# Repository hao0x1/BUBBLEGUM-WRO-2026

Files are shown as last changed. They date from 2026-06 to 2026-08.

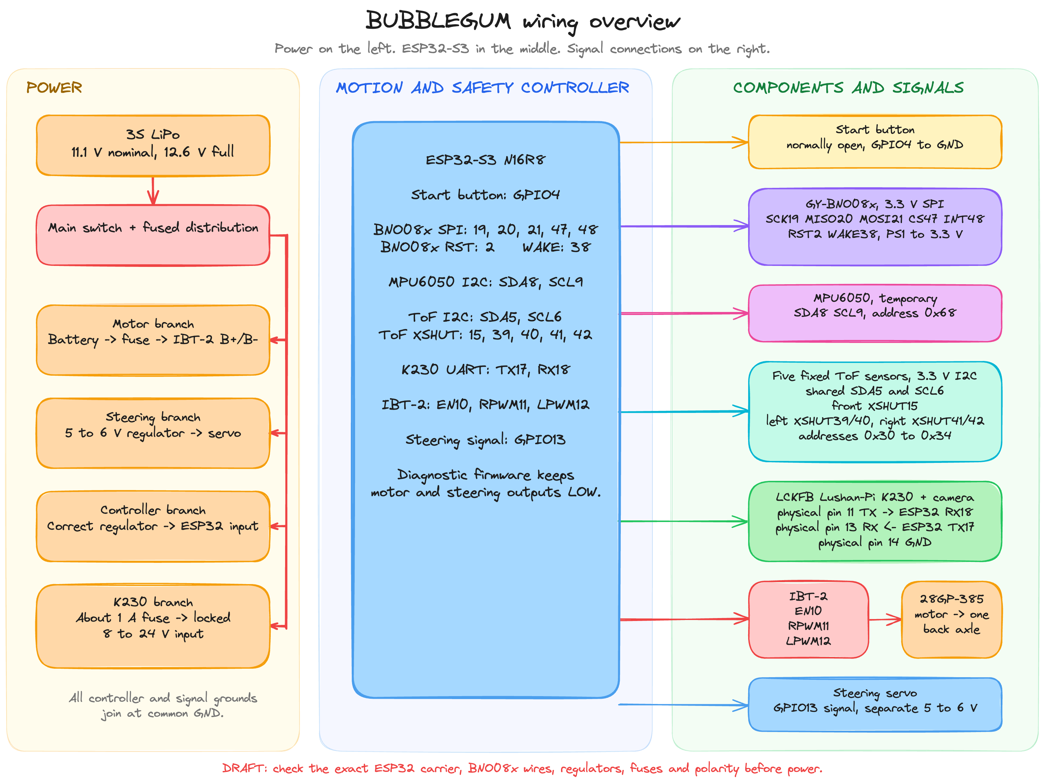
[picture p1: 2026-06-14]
schemes/wiring-overview.png

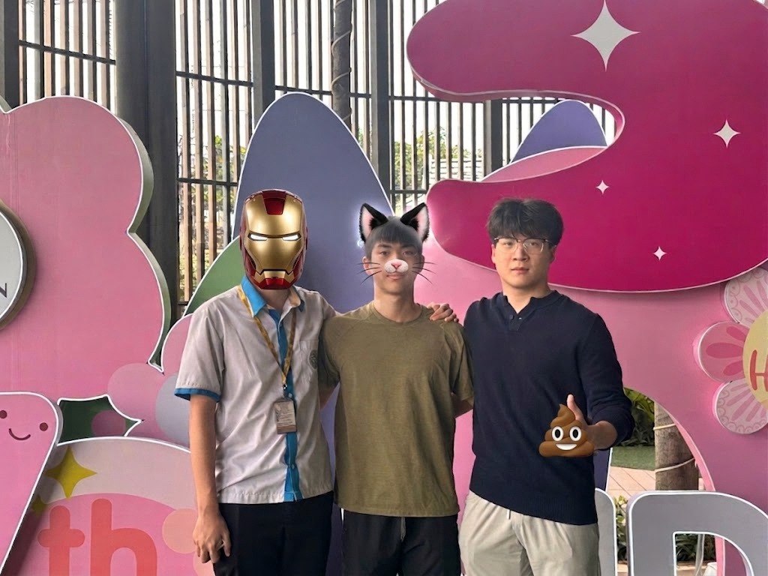
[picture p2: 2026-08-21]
t-photos/funny_img.jpeg

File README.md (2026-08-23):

# BUBBLEGUM WRO Future Engineers 2026

Competition source and field tools for our ESP32-S3 / Lushan-Pi K230 car.

**Start here: [competition/QUICK_START.md](competition/QUICK_START.md).** It contains the exact upload and logging commands for both rounds. No assistant or internet access is needed on the prepared laptop.

## Which version to use

| Round / board | Selection | Evidence |
| --- | --- | --- |
| Open — ESP32 | `autonomousOpen`, R18 configuration | Previously completed 12 corners / three laps in the physical Open test. Speed settings are unchanged. |
| Obstacle — ESP32 | `autonomousObstacle`, R42 | Latest recovery/progress revision; built and host-tested, awaiting its field run. Three laps, normal start, no parking. |
| Either round — K230 | [main.py](src/LCKFB-Lushan-Pi-K230/main.py) | Same production camera program for both rounds. Existing SD colour calibration is preserved. |

From this repository on the prepared Mac:

```sh
./competition/field.sh open
```

or:

```sh
./competition/field.sh obstacle
```

Each command builds/uploads the selected ESP32 profile and opens a passive log. The car waits for its physical start button. Wait for the logger's `READY` message, then press the start button once. `READY` confirms `WAIT_BUTTON` with healthy telemetry and no controller or actuator fault. Logs are saved in `local/logs/`.

## Current behavior

The ESP32 reads five ToF distance sensors and an XMS-A5/BNO055 heading sensor, drives the steering servo and motor, and counts verified corner exits. Twelve corners form three laps. The K230 reports red/green image observations over UART; it does not command motors.

Open uses its existing R18 speed and corner settings. Obstacle uses 400-permille straight power, 450 for tight corners, and 300 for bounded reverse. It follows live red-right / green-left guidance when usable, continues through measured free space when a target disappears, and attempts recovery when blocked. Pillar-section learning is disabled; a known failed target is briefly suppressed after reversing to avoid immediately repeating the same maneuver. Distance sensors remain active during that suppression. Parking and parking-lot departure are not part of this competition revision.

The front-left/front-right sensors are mounted narrower than the rear pair; the four side rays point outward at approximately 45 degrees. Their raw front-minus-rear distances are not treated as calibrated wall angles. The source pin mapping is in [boardConfig.h](src/ESP32-S3-N16R8/include/boardConfig.h).

## Repository layout

- [src/ESP32-S3-N16R8](src/ESP32-S3-N16R8): current PlatformIO controller, sensors, actuators and configuration.
- [src/LCKFB-Lushan-Pi-K230](src/LCKFB-Lushan-Pi-K230): production camera program.
- [competition](competition): short field guide and upload/log command.
- [tools](tools): portable logger, K230 installer/calibrator and offline checks.
- [tests](tests): host regression tests for the controller and actuator driver.
- [competition.md](competition.md): supplied competition reference.
- [models](models), [schemes](schemes), [other](other): CAD, wiring drawings and component records.
- [t-photos](t-photos), [v-photos](v-photos), [video](video): team/vehicle photos and driving-video link.
- `local/`: ignored logs, firmware copies, old experiments, backups and private test records. Keep this folder on the laptop; it is excluded from Git.

Some hardware drawings and component records predate the latest electronics changes. The current source and field guide identify the configuration prepared for this run.

## Offline checks

```sh
./tools/check.sh
./competition/field.sh build
```

Host tests exercise state transitions, mirrored steering, recovery timing and three-lap completion. They do not establish a successful physical Obstacle run. The field guide identifies the remaining physical verification. No Git commit or push is performed by the field tools.

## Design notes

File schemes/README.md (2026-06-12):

# Wiring

This is the working wiring map for our car. It matches the wiring we are checking now.

The readable overview is in [`wiring-overview.png`](wiring-overview.png). We can edit the original drawing in [`wiring-overview.excalidraw`](wiring-overview.excalidraw).

Do not power the car from this page yet. We still need a clear ESP32 carrier photo and a yes/no check of the soldered BNO08x wires. The current firmware is safe diagnostics only, but a wrong pin map can still damage two outputs connected together.

## Start button

The button goes between GPIO4 and GND:

```text
ESP32 GPIO4 ---- normally-open button ---- GND
```

The button has no positive or negative side. On a four-leg tactile button, two legs can already be connected inside. Use a multimeter and choose one leg from each different contact group. The selected legs must be open when released and near 0 ohms only while pressed.

The ESP32 uses `INPUT_PULLUP`:

| Button state | GPIO4 reading |
|---|---|
| Released | HIGH |
| Pressed | LOW |

## ESP32-S3 pin map

| ESP32 GPIO | Connection |
|---:|---|
| 2 | BNO08x `RST` |
| 4 | Start button to GND |
| 5 | SDA for all five ToF sensors |
| 6 | SCL for all five ToF sensors |
| 8 | MPU6050 `SDA` |
| 9 | MPU6050 `SCL` |
| 10 | IBT-2 `R_EN` and `L_EN`, tied together |
| 11 | IBT-2 `RPWM` |
| 12 | IBT-2 `LPWM` |
| 13 | Steering-servo signal |
| 15 | Front VL53L1X `XSHUT` |
| 17 | ESP32 TX to K230 physical pin 13 RX |
| 18 | ESP32 RX from K230 physical pin 11 TX |
| 19 | BNO08x `SCL/SCK/RX`, SPI clock |
| 20 | BNO08x `SDA/MISO/TX`, SPI MISO |
| 21 | BNO08x `AD0/MOSI`, SPI MOSI |
| 38 | BNO08x `PS0/WAKE` |
| 39 | Front-left VL53L4CD `XSHUT` |
| 40 | Back-left VL53L4CD `XSHUT` |
| 41 | Front-right VL53L4CD `XSHUT` |
| 42 | Back-right VL53L4CD `XSHUT` |
| 47 | BNO08x `CS` |
| 48 | BNO08x `INT` |

GPIO19 and GPIO20 are also the ESP32-S3 native USB pins. When the BNO08x harness is connected, use the board's separate USB-to-UART `COM` connector for flashing and serial logs. Do not use the native `USB` connector.

GPIO0, GPIO3, GPIO45, and GPIO46 are boot-configuration pins, so we do not use them for this harness. GPIO35 through GPIO37 are unavailable with the N16R8 octal PSRAM module.

Some dual-USB ESP32-S3 carrier boards put the onboard RGB data input on GPIO48. If ours is one of those boards, the BNO08x interrupt shares that net. Do not initialize the onboard RGB LED. We need the exact carrier revision before we call this final.

## BNO08x rewiring

The working record says only these two wires still need to move:

| BNO08x pin | Soldered now | Move to |
|---|---:|---:|
| `RST` | GPIO45 | GPIO2 |
| `PS0/WAKE` | GPIO0 | GPIO38 |

Keep this full BNO08x map if it matches the real soldered harness:

| BNO08x label | Connection |
|---|---|
| `VCC` or `VCC_3.3V` | ESP32 3.3 V only |
| `GND` | GND |
| `SCL/SCK/RX` | GPIO19 |
| `SDA/MISO/TX` | GPIO20 |
| `AD0/MOSI` | GPIO21 |
| `CS` | GPIO47 |
| `INT` | GPIO48 |
| `RST` | GPIO2 |
| `PS1` | 3.3 V |
| `PS0/WAKE` | GPIO38 |
| `BOOT` test pad | Not connected |

Leave the PS0 and PS1 solder bridges open if the header wires set both pins. Do not hard-wire PS0 to 3.3 V while GPIO38 is also connected. Firmware drives GPIO38 HIGH before it resets the BNO08x so the sensor selects SPI mode.

Before changing the two wires, disconnect every battery, USB cable, buck converter, motor supply, and servo supply. Check continuity after soldering and check for shorts from 3.3 V to GND before power-on.

## Five ToF sensors

All five ToF boards share regulated 3.3 V, GND, SDA GPIO5, and SCL GPIO6.

| Position | Sensor | Direction | XSHUT | Address after boot |
|---|---|---|---:|---:|
| Front-centre | VL53L1X | Forward | GPIO15 | `0x30` |
| Front-left | VL53L4CD | Left | GPIO39 | `0x31` |
| Back-left | VL53L4CD | Left | GPIO40 | `0x32` |
| Front-right | VL53L4CD | Right | GPIO41 | `0x33` |
| Back-right | VL53L4CD | Right | GPIO42 | `0x34` |

Leave each ToF `GPIO` or `GPIO1` pin disconnected. The ESP32 uses the individual XSHUT wires to start and readdress the boards one at a time.

The front module seller description was unclear, so we still need to check that it is really a VL53L1X and not a VL53L0X.

## MPU6050

| MPU6050 pin | Connection |
|---|---|
| `VCC` | 3.3 V |
| `GND` | GND |
| `SDA` | GPIO8 |
| `SCL` | GPIO9 |
| `AD0` | GND, address `0x68` |
| `XDA`, `XCL`, `INT` | Not connected |

The MPU6050 is temporary comparison hardware. We plan to remove it after the BNO08x is physically tested.

## K230 UART

UART is 115200 baud, 8N1, and 3.3 V logic.

| K230 physical header pin | K230 signal | ESP32 |
|---:|---|---:|
| 11 | GPIO5, UART2 TX | GPIO18 RX |
| 13 | GPIO6, UART2 RX | GPIO17 TX |
| 14 | GND | GND |

Connect TX, RX, and GND only. Do not connect 5 V or 3.3 V between the two controllers.

## IBT-2, motor, and steering

| Part | Connection |
|---|---|
| IBT-2 `VCC` | Regulated 5 V logic supply |
| IBT-2 `GND` | Common GND |
| IBT-2 `R_EN` and `L_EN` | GPIO10 |
| IBT-2 `RPWM` | GPIO11 |
| IBT-2 `LPWM` | GPIO12 |
| Steering-servo signal | GPIO13 |
| Steering-servo power | Separate regulated 5 to 6 V supply |
| Steering-servo GND | Common GND |

Never power the servo from ESP32 3.3 V. The current firmware forces GPIO10, GPIO11, GPIO12, and GPIO13 LOW and creates no PWM.

## Power overview

```text
3S LiPo
  |
  +-- main switch and fused branch --> IBT-2 motor power
  +-- correct regulated branch -----> ESP32 board input
  +-- 5 to 6 V regulated branch ----> steering servo
  +-- fused 8 to 24 V branch -------> K230 locked 2-pin input

All controller and signal grounds join at common GND.
```

We still need the real regulator models, fuse values, wire sizes, and physical power-distribution photo before turning this into the final diagram.

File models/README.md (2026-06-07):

# CAD and fabrication models

- `Ackermann Chassis CLEAN Named Assembly.f3z` — the editable Fusion assembly
  of the chassis. Stored with Git LFS, so clone with `git lfs install` first.
- Printable exports and STL files land here once the parts are frozen and the
  print settings that survived testing are recorded.
- For every external model we adapt, we record the units, material, revision,
  source and license before it goes in.

The assembly has not been physically verified yet. Verification needs the
ready-to-run envelope with steering straight, full-left and full-right, plus
mass, wheelbase, track width, tyre size and the mechanically coupled driving
axle.

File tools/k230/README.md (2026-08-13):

# K230 competition deployment

Use the same K230 program for both rounds. Open uses ESP32 distance sensors and
the IMU and does not require camera observations. Obstacle uses the K230 camera
when a red or green pillar is visible. Parking is disabled.

The current K230 production program and its color calibration are unchanged by
the final ESP32 recovery update. If this program is already installed and the
camera is working, leave the K230 as it is; switching rounds only requires the
ESP32 firmware change described in the competition guide.

## Install production, only if needed

1. Connect the K230 to the computer and open
   [`installProduction.py`](installProduction.py) in VS Code.
2. Select the K230 in the existing CanMV extension, then run the command
   **CanMV: Run Active File on K230** with this installer as the active file.
3. Wait for this exact terminal message:

   ```text
   INSTALL OK: /sdcard/main.py VERIFIED
   ```

4. Restart the K230. Its startup runs `/sdcard/main.py`; simply running the
   installer from RAM does not start camera detection.

The installer writes `/sdcard/main.py`, verifies the bytes on the SD card, and
retains the prior program as `/sdcard/main.py.bak`. It does not change
`/sdcard/colorThresholds.cfg` or `/sdcard/colorThresholds.bak`. A missing success
message means installation is not confirmed; read the reported error.

Do not save the installer or the calibrator as the board's startup `main.py`.
The actual production source is
[`../../src/LCKFB-Lushan-Pi-K230/main.py`](../../src/LCKFB-Lushan-Pi-K230/main.py).

## Color calibration, only if field lighting requires it

Keep the existing calibration unless pillar detection fails under the new
lighting. This step changes the saved LAB thresholds.

1. Open [`colorCalibration.py`](colorCalibration.py) and use
   **CanMV: Run Active File on K230**.
2. Keep the car still. Fill the preview's RED and GREEN boxes with flat faces
   of the corresponding pillars, keeping the EMPTY MAT box clear.
3. Allow the 15-second alignment period and sampling to finish. A valid result
   prints:

   ```text
   COLOR CALIBRATION SAVED: /sdcard/colorThresholds.cfg
   RED/GREEN SAVED; PARKING/MAGENTA REMAINS DISABLED
   ```

4. Restart the K230 to return to production detection. It loads the saved
   calibration automatically. The startup message
   `PERSISTED COLOR CONFIG LOADED: field detection not yet proven` confirms
   loading; it does not prove the current pillars are being detected.

An invalid sample is not saved. The previous valid file is retained as
`/sdcard/colorThresholds.bak`. Do not manually guess LAB values at the field.

## Verify this package on the computer

```sh
cd /Users/zhihaowu/futureEngineers/BUBBLEGUM-WRO-2026
python3 tools/k230/verifyInstaller.py
```

The check statically extracts the installer's embedded bytes and compares them
with the repository's production source, without running board code. This
package embeds **71,099 bytes**, SHA-256
`afb31d3ea162104ad637e817fcba875e67b478f583328634a1da4dfa348ffa0d`.
If production `main.py` changes later, regenerate the installer before deploying;
this check will reject an outdated embedded payload.

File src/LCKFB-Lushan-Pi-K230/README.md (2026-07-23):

# K230 production camera program

[`main.py`](main.py) is the program installed as `/sdcard/main.py` on the
Lushan Pi K230. It sends camera observations to the ESP32 at 115200 baud on
GPIO 5 (TX) and GPIO 6 (RX). The ESP32 controls steering, drive, lap counting,
and recovery.

Use this same K230 program for Open and Obstacle. Open does not require camera
observations. Obstacle uses visible red/green pillars; parking is disabled.
The final obstacle recovery revision changes ESP32 behavior and leaves this
camera program unchanged.

Deployment and optional color calibration are documented in
[`tools/k230/README.md`](../../tools/k230/README.md). The installer preserves the
board's saved `/sdcard/colorThresholds.cfg`; there is no generic calibration
file to copy over the car's measured thresholds.

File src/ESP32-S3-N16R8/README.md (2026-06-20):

# ESP32-S3 controller

Use [the competition guide](../../competition/QUICK_START.md) from the repository root.

| PlatformIO environment | Purpose |
| --- | --- |
| `autonomousOpen` | Open round, R18 configuration, three laps |
| `autonomousObstacle` | Obstacle round, R42, three laps, normal start, parking disabled |
| `dryRun` | Diagnostics with actuator code disabled; not a competition driving build |
| `obstacleSinglePassCalibration` | Historical strict single-pillar test; not the full obstacle round |
| `autonomous` | Compatibility alias for `autonomousOpen` |

Build without connecting a board:

```sh
../../competition/field.sh build
```

Or from the repository root:

```sh
./competition/field.sh open
./competition/field.sh obstacle
```

These are alternative uploads to the same ESP32, not two programs installed together. Both use the same K230 camera program. Open does not require camera observations to drive; Obstacle requires a fresh camera connection but no visible pillar is required for ordinary clear-space travel.

`include/controllerProfiles.h` and `src/controllerProfiles.cpp` define the exact tested profiles. `main.cpp` samples sensors, applies decisions and logs telemetry. `autonomyController.cpp` owns navigation and recovery. `vehicleActuators.cpp` owns PWM, direction-neutral timing and the motor command lease.

Positive steering is right; positive drive is forward. The motor starts only after a physical button press. Closing the logger does not stop the car. A completed run or latched fault requires a reset before the next start.

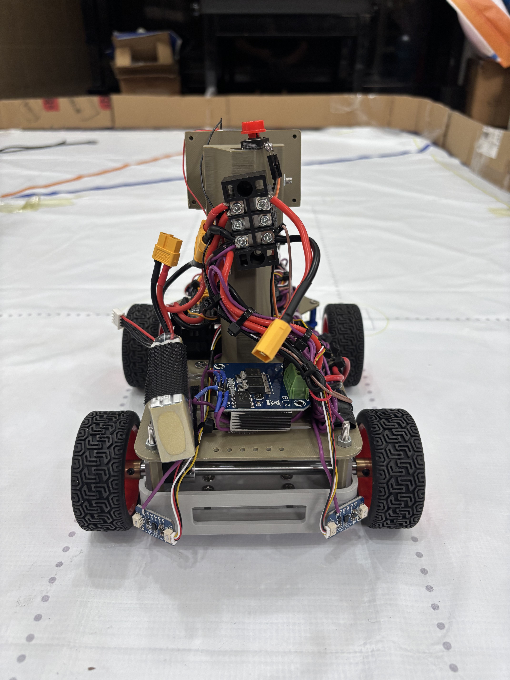
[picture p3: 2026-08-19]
v-photos/rear-view.jpeg

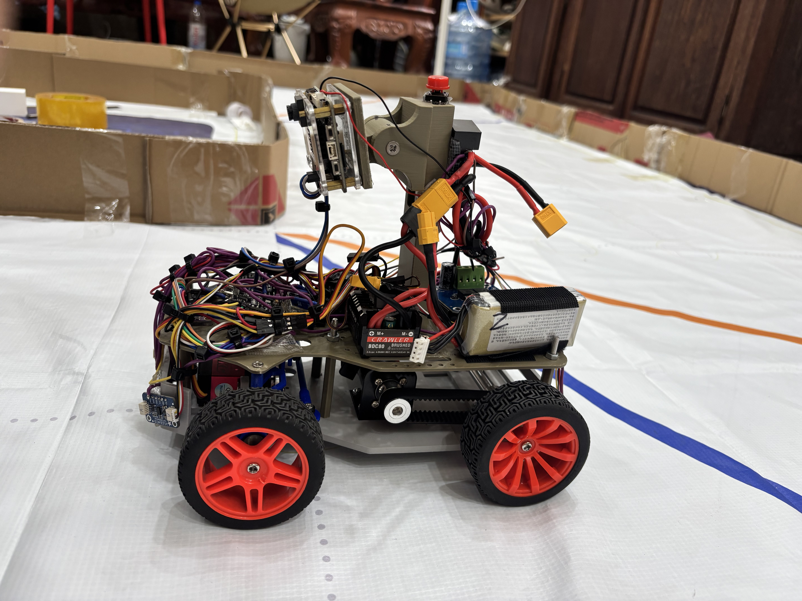
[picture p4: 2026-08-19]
v-photos/left-side-view.jpeg

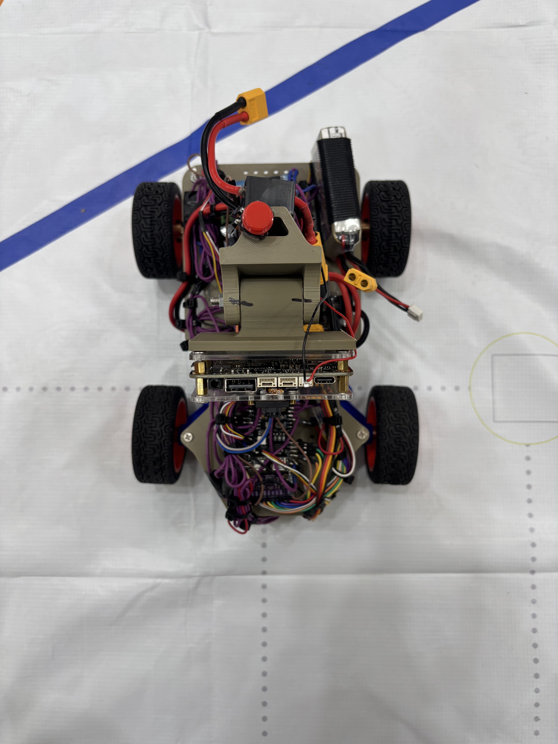
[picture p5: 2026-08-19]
v-photos/top-view.jpeg

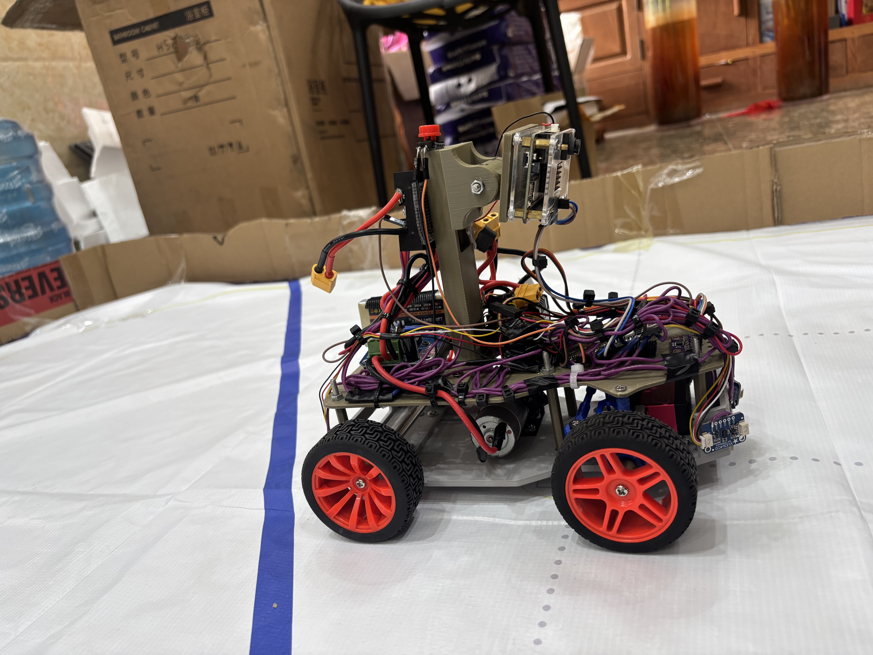
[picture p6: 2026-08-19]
v-photos/right-side-view.jpeg

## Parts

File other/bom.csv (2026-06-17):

subsystem | component | quantity | status | what_we_still_need
vision | LCKFB Lushan-Pi K230 CanMV board standard 1 GB layout | 1 | confirm | clear photo of the board name and revision
vision | GC2093 camera module and lens exact version unknown | 1 | confirm | clear photo of the camera and lens marking
control | ESP32-S3-WROOM-1-N16R8 module on a dual-USB carrier | 1 | confirm | clear photo of carrier name revision and COM USB labels
orientation | GY-BNO08x purple carrier | 1 | rewiring | readable BNO080 or BNO085 chip marking and final continuity check
comparison | MPU6050 breakout | 1 | temporary | remove after the BNO08x passes the real test unless measurements justify it
distance | VL53L1X front-centre module | 1 | confirm | readable sensor or seller variant marking
distance | VL53L4CD side module | 4 | installed | physical I2C enumeration test
drive | 28GP-385 12 V approximately 500 rpm 16:1 brushed planetary gearmotor | 1 | confirm | photo of the motor and gearbox label
drive | IBT-2 BTS7960 brushed motor driver | 1 | installed | raised-wheel direction current and braking test
drive | common back axle belt gears or differential exact parts unknown | 1 set | confirm | photos and measurements of the final mechanical connection
drive | normal vehicle wheels exact model and size unknown | 4 | confirm | wheel diameter width hub and final mounting photos
steering | steering servo exact model unknown | 1 | confirm | photo of the servo label and measured safe pulse limits
power | 3S 11.1 V 1100 mAh 25C LiPo | 1 | confirm | photo of battery label and connector polarity
power | main vehicle power switch exact model unknown | 1 | confirm | photo and current rating
power | motor and K230 inline fuses exact holders and values unknown | 1 set | confirm | photos and fuse values chosen from measured current
power | ESP32 regulator exact model unknown | 1 | confirm | input range output voltage current rating and photo
power | steering 5 to 6 V buck converter exact model unknown | 1 | confirm | input range output voltage current rating and photo
start | four-leg normally-open momentary tactile button | 1 | not soldered | continuity test then GPIO4 to GND

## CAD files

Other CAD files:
models/Ackermann Chassis CLEAN Named Assembly.f3z

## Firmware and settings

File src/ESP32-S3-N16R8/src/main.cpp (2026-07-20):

#include <Arduino.h>
#include <Wire.h>

#include "autonomyController.h"
#include "boardConfig.h"
#include "controllerProfiles.h"
#include "imuSensors.h"
#include "tofSensors.h"
#include "visionProtocol.h"

#ifndef BUBBLEGUM_ENABLE_ACTUATION
#define BUBBLEGUM_ENABLE_ACTUATION 0
#endif

#ifndef BUBBLEGUM_ACTUATOR_CALIBRATION_CONFIRMED
#define BUBBLEGUM_ACTUATOR_CALIBRATION_CONFIRMED 0
#endif

#define BUBBLEGUM_AUTONOMY_PROFILE_OPEN 1
#define BUBBLEGUM_AUTONOMY_PROFILE_OBSTACLE 2

#ifndef BUBBLEGUM_AUTONOMY_PROFILE
#define BUBBLEGUM_AUTONOMY_PROFILE BUBBLEGUM_AUTONOMY_PROFILE_OPEN
#endif

#ifndef BUBBLEGUM_OBSTACLE_SINGLE_PASS_CALIBRATION
#define BUBBLEGUM_OBSTACLE_SINGLE_PASS_CALIBRATION 0
#endif

#ifndef BUBBLEGUM_CALIBRATION_MAX_RUN_MS
#define BUBBLEGUM_CALIBRATION_MAX_RUN_MS 8000
#endif

static_assert(BUBBLEGUM_ENABLE_ACTUATION == 0 ||
                  BUBBLEGUM_ENABLE_ACTUATION == 1,
              "BUBBLEGUM_ENABLE_ACTUATION must be 0 or 1");
static_assert(BUBBLEGUM_ACTUATOR_CALIBRATION_CONFIRMED == 0 ||
                  BUBBLEGUM_ACTUATOR_CALIBRATION_CONFIRMED == 1,
              "BUBBLEGUM_ACTUATOR_CALIBRATION_CONFIRMED must be 0 or 1");
static_assert(BUBBLEGUM_AUTONOMY_PROFILE == BUBBLEGUM_AUTONOMY_PROFILE_OPEN ||
                  BUBBLEGUM_AUTONOMY_PROFILE ==
                      BUBBLEGUM_AUTONOMY_PROFILE_OBSTACLE,
              "BUBBLEGUM_AUTONOMY_PROFILE must select OPEN (1) or OBSTACLE (2)");
static_assert(BUBBLEGUM_OBSTACLE_SINGLE_PASS_CALIBRATION == 0 ||
                  BUBBLEGUM_OBSTACLE_SINGLE_PASS_CALIBRATION == 1,
              "BUBBLEGUM_OBSTACLE_SINGLE_PASS_CALIBRATION must be 0 or 1");

#if BUBBLEGUM_OBSTACLE_SINGLE_PASS_CALIBRATION
static_assert(BUBBLEGUM_ENABLE_ACTUATION == 1,
              "single-pass calibration requires actuation");
static_assert(BUBBLEGUM_AUTONOMY_PROFILE ==
                  BUBBLEGUM_AUTONOMY_PROFILE_OBSTACLE,
              "single-pass calibration requires the Obstacle profile");
static_assert(BUBBLEGUM_CALIBRATION_MAX_RUN_MS >= 1000,
              "single-pass calibration runtime is too short");
#endif

#if BUBBLEGUM_ENABLE_ACTUATION && \
    !BUBBLEGUM_ACTUATOR_CALIBRATION_CONFIRMED
#error "Run the wheels-up actuator calibration, then set BUBBLEGUM_ACTUATOR_CALIBRATION_CONFIRMED=1"
#endif

#if BUBBLEGUM_ENABLE_ACTUATION
#include "runBlackBox.h"
#include "vehicleActuators.h"
#endif

namespace {

constexpr uint32_t SERIAL_BAUD = 115200;
constexpr uint32_t HEALTH_STABLE_MS = 1000;
constexpr uint32_t STARTUP_FRONT_CLEAR_HOLD_MS = 250;
constexpr uint8_t MINIMUM_START_GYRO_CALIBRATION = 2;
constexpr uint32_t SERVO_SETTLE_MS = 700;
constexpr uint32_t TELEMETRY_INTERVAL_MS = 100;
constexpr uint32_t SENSOR_SUMMARY_INTERVAL_MS = 1000;

HardwareSerial k230Serial(1);
TofSensors tof;
ImuSensors imuSensors;
vision::Decoder visionDecoder;

#if BUBBLEGUM_AUTONOMY_PROFILE == BUBBLEGUM_AUTONOMY_PROFILE_OBSTACLE
constexpr autonomy::ChallengeProfile CONTROLLER_PROFILE =
    autonomy::ChallengeProfile::Obstacle;
#else
constexpr autonomy::ChallengeProfile CONTROLLER_PROFILE =
    autonomy::ChallengeProfile::Open;
#endif

autonomy::Config makeBuildControllerConfig() {
  autonomy::Config config =
      CONTROLLER_PROFILE == autonomy::ChallengeProfile::Obstacle
          ? autonomy::makeGuardedObstacleConfig()
          : autonomy::makeControllerConfig(CONTROLLER_PROFILE);
#if BUBBLEGUM_OBSTACLE_SINGLE_PASS_CALIBRATION
  config.stopAfterFirstVerifiedObstaclePass = true;
  config.preferForwardObstacleProgress = false;
  config.maxRunMs = BUBBLEGUM_CALIBRATION_MAX_RUN_MS;
#endif
  return config;
}

autonomy::Controller controller(makeBuildControllerConfig());

#if BUBBLEGUM_ENABLE_ACTUATION
VehicleActuators::Config makeActuatorConfig() {
  VehicleActuators::Config config;
  // Measured on the assembled Ackermann linkage on 2026-09-01. The physical
  // endpoints were 900/2100 us, so autonomous travel keeps a 20 us inset.
  config.steeringLeftPulseUs = 920;
  config.steeringCenterPulseUs = 1500;
  config.steeringRightPulseUs = 2080;
  config.steeringReversed = false;
  config.forwardUsesRpwm = true;
  return config;
}

VehicleActuators actuators(makeActuatorConfig());
runblackbox::Recorder runBlackBox;
bool actuatorsStarted = false;
bool actuatorFault = false;
uint32_t actuatorsStartedAtMs = 0;
uint16_t appliedDrivePermille = 0;
uint32_t lastAppliedDriveRampMs = 0;

uint16_t rampAppliedDrive(uint16_t requestedPermille, uint32_t nowMs) {
  if (requestedPermille <= appliedDrivePermille) {
    appliedDrivePermille = requestedPermille;
    lastAppliedDriveRampMs = nowMs;
    return appliedDrivePermille;
  }
  if (appliedDrivePermille == 0U &&
      requestedPermille >= controller.config().minimumMovingSpeedPermille) {
    appliedDrivePermille = controller.config().minimumMovingSpeedPermille;
    lastAppliedDriveRampMs = nowMs;
    return appliedDrivePermille;
  }
  const uint32_t elapsedMs =
      static_cast<uint32_t>(nowMs - lastAppliedDriveRampMs);
  const uint32_t rise =
      (static_cast<uint32_t>(controller.config().accelerationPermillePerSecond) *
       elapsedMs) /
      1000U;
  if (rise == 0U) return appliedDrivePermille;
  const uint32_t next = static_cast<uint32_t>(appliedDrivePermille) + rise;
  appliedDrivePermille = static_cast<uint16_t>(
      next < requestedPermille ? next : requestedPermille);
  lastAppliedDriveRampMs = nowMs;
  return appliedDrivePermille;
}
#endif

bool xmsI2cStarted = false;
bool tofI2cStarted = false;
bool protocolOkay = false;
bool healthCandidateActive = false;
bool healthStable = false;
uint32_t healthCandidateSinceMs = 0;
bool startupFrontClearHeld = false;
uint32_t startupFrontClearSeenAtMs = 0;
uint32_t lastTelemetryMs = 0;
uint32_t lastSensorSummaryMs = 0;
uint32_t bootSessionId = 0;
uint32_t currentRunId = 0;

autonomy::RunState lastState = autonomy::RunState::WaitingForHealth;
autonomy::CourseDirection lastDirection = autonomy::CourseDirection::Unknown;
autonomy::ObstacleTarget lastObstacle = autonomy::ObstacleTarget::None;
uint32_t lastFaultFlags = autonomy::FaultNone;
uint8_t lastCornerCount = 0;
bool previousStartLatched = false;

void forceOutputsLow() {
  for (uint8_t pin : board::MOTOR_SAFE_PINS) {
    digitalWrite(pin, LOW);
    pinMode(pin, OUTPUT);
    digitalWrite(pin, LOW);
  }
  digitalWrite(board::STEERING_SERVO_PIN, LOW);
  pinMode(board::STEERING_SERVO_PIN, OUTPUT);
  digitalWrite(board::STEERING_SERVO_PIN, LOW);
}

bool beginI2cBus(TwoWire& wire, const __FlashStringHelper* name,
                 uint8_t sdaPin, uint8_t sclPin,
                 uint32_t clockHz = board::I2C_CLOCK_HZ) {
  const bool started = wire.begin(sdaPin, sclPin, clockHz);
  if (started) {
    wire.setTimeOut(board::I2C_TIMEOUT_MS);
    wire.setClock(clockHz);
  }
  Serial.print(F("[i2c/"));
  Serial.print(name);
  Serial.print(F("] SDA=GPIO"));
  Serial.print(sdaPin);
  Serial.print(F(" SCL=GPIO"));
  Serial.print(sclPin);
  Serial.print(F(" begin="));
  Serial.println(started ? F("ok") : F("failed"));
  return started;
}

const char* stateName(autonomy::RunState state) {
  switch (state) {
    case autonomy::RunState::WaitingForHealth:
      return "WAIT_HEALTH";
    case autonomy::RunState::WaitingForStart:
      return "WAIT_BUTTON";
    case autonomy::RunState::DirectionProbe:
      return "DIRECTION_PROBE";
    case autonomy::RunState::Running:
      return "STRAIGHT";
    case autonomy::RunState::Cornering:
      return "CORNER";
    case autonomy::RunState::FinishDelay:
      return "FINISH_CLEAR";
    case autonomy::RunState::Finished:
      return "FINISHED";
    case autonomy::RunState::FaultLatched:
      return "FAULT_LATCHED";
    case autonomy::RunState::Parking:
      return "PARKING_LOCKED";
  }
  return "UNKNOWN";
}

const char* directionName(autonomy::CourseDirection direction) {
  switch (direction) {
    case autonomy::CourseDirection::Unknown:
      return "UNKNOWN";
    case autonomy::CourseDirection::Clockwise:
      return "CLOCKWISE";
    case autonomy::CourseDirection::CounterClockwise:
      return "COUNTERCLOCKWISE";
  }
  return "UNKNOWN";
}

const char* obstacleName(autonomy::ObstacleTarget obstacle) {
  switch (obstacle) {
    case autonomy::ObstacleTarget::None:
      return "NONE";
    case autonomy::ObstacleTarget::RedPassRight:
      return "RED_PASS_RIGHT";
    case autonomy::ObstacleTarget::GreenPassLeft:
      return "GREEN_PASS_LEFT";
  }
  return "NONE";
}

autonomy::RangeReading rangeReading(const TofSensors::Sample& sample) {
  autonomy::RangeReading reading;
  reading.online = sample.online && sample.sampleCount > 0U &&
                   sample.i2cStatus == 0U;
  reading.valid = reading.online && sample.valid;
  reading.rangeMm = sample.rangeMm;
  reading.updatedAtMs = sample.lastUpdateMs;
  reading.rangeStatus = sample.rangeStatus;
  reading.i2cStatus = sample.i2cStatus;
  return reading;
}

autonomy::BlobReading blobReading(const vision::Blob& blob, bool present) {
  autonomy::BlobReading reading;
  reading.present = present;
  if (!present) return reading;
  reading.centerX = blob.centerX;
  reading.bottomY = blob.bottomY;
  reading.width = blob.width;
  reading.height = blob.height;
  reading.confidence = blob.confidence;
  return reading;
}

bool cameraRawHealthy(uint32_t nowMs) {
  if (!visionDecoder.observationFresh(nowMs,
                                      controller.config().visionStaleMs)) {
    return false;
  }
  return visionDecoder.observation().has(vision::CameraValid);
}

bool tofResponding(const TofSensors::Sample& sample, uint32_t nowMs,
                   uint32_t maximumAgeMs) {
  return sample.online && sample.i2cStatus == 0U && sample.sampleCount > 0U &&
         static_cast<uint32_t>(nowMs - sample.lastUpdateMs) <= maximumAgeMs;
}

bool opticalNoTargetStatus(uint8_t status) {
  // 7 is ST's wrapped-target/phase-mismatch result. Status 6 is also a fresh
  // nonfatal measurement (valid without the wraparound check). On side
  // VL53L4CDs we keep it degraded rather than inventing a usable range; on the
  // front VL53L1X the acquisition layer accepts its numeric range directly.
  // None of these statuses is an I2C or module-presence failure.
  return status == 1U || status == 2U || status == 4U || status == 6U ||
         status == 7U;
}

bool sideGeometryRawHealthy(uint32_t nowMs, bool allowCrossPair) {
  const uint32_t maximumAgeMs = controller.config().sensorStaleMs;
  const TofSensors::Sample* const sides[] = {
      &tof.frontLeft(), &tof.backLeft(), &tof.frontRight(), &tof.backRight()};
  bool valid[4] = {false, false, false, false};

  for (uint8_t i = 0; i < 4U; ++i) {
    // An invalid range is tolerable only when the module itself is still
    // responding. A loose wire or stale sensor continues to block motion.
    if (!tofResponding(*sides[i], nowMs, maximumAgeMs)) return false;
    if (!sides[i]->valid && !opticalNoTargetStatus(sides[i]->rangeStatus)) {
      return false;
    }
    valid[i] = TofSensors::sampleFresh(*sides[i], nowMs, maximumAgeMs) &&
               sides[i]->rangeMm <=
                   controller.config().openingReferenceMaximumMm;
  }

  // Open Challenge has no pillars and does not need a numeric wall solution
  // merely to arm. A real no-target can occur at the legal start when an
  // angled ray looks past a 100 mm wall. All four modules were still required
  // above to answer electrically, freshly, and with a recognized status.
  // Obstacle Challenge keeps the stricter geometry gate.
  if (!controller.config().obstacleAvoidanceEnabled) return true;
  if (controller.config().guardedObstaclePassEnabled) {
    return valid[0] || valid[1] || valid[2] || valid[3];
  }

  // Accept any actual straight-geometry solution: complete A/B on the left,
  // complete C/D on the right, or both forward A/C rays. While stopped, the
  // caller may also allow one local numeric ray on each side when the centre
  // front is independently clear. That cross-pair is only an arming gate and
  // never receives wall/lateral steering authority. All four modules were
  // already required to answer electrically and freshly above, so this does
  // not hide a loose wire, stale module, or bus failure.
  const bool anyLeft = valid[0] || valid[1];
  const bool anyRight = valid[2] || valid[3];
  return (valid[0] && valid[1]) || (valid[2] && valid[3]) ||
         (valid[0] && valid[2]) ||
         (allowCrossPair && anyLeft && anyRight);
}

bool sensorsRawHealthy(uint32_t nowMs) {
  const TofSensors::Sample& front = tof.front();
  // A fresh optical no-target is allowed at the start: the wall may simply be
  // beyond the current ray. Status 3 is different—it means too close.
  const bool frontResponding =
      tofResponding(front, nowMs, controller.config().sensorStaleMs) &&
      (front.valid || opticalNoTargetStatus(front.rangeStatus));
  const bool frontNumericNow =
      TofSensors::sampleFresh(front, nowMs,
                              controller.config().sensorStaleMs);
  const bool frontClearNow =
      frontNumericNow &&
      front.rangeMm > controller.config().directionProbeAbortFrontMm;
  if (frontClearNow) {
    startupFrontClearHeld = true;
    startupFrontClearSeenAtMs = nowMs;
  } else if (!frontResponding || front.rangeStatus != 7U ||
             (startupFrontClearHeld &&
              static_cast<uint32_t>(nowMs - startupFrontClearSeenAtMs) >=
                  STARTUP_FRONT_CLEAR_HOLD_MS)) {
    startupFrontClearHeld = false;
    startupFrontClearSeenAtMs = 0;
  }
  const bool frontClearForCross =
      frontClearNow ||
      (startupFrontClearHeld &&
       static_cast<uint32_t>(nowMs - startupFrontClearSeenAtMs) <
           STARTUP_FRONT_CLEAR_HOLD_MS);
  return protocolOkay &&
         imuSensors.bnoFresh(nowMs, controller.config().sensorStaleMs) &&
         imuSensors.bnoAccuracy() >= MINIMUM_START_GYRO_CALIBRATION &&
         frontResponding &&
         sideGeometryRawHealthy(nowMs, frontClearForCross) &&
         (!controller.config().requireVisionForMotion || cameraRawHealthy(nowMs));
}

void updateHealthGate(uint32_t nowMs) {
  const bool rawHealthy = sensorsRawHealthy(nowMs);
  if (!rawHealthy) {
    healthCandidateActive = false;
    healthStable = false;
    return;
  }
  if (!healthCandidateActive) {
    healthCandidateActive = true;
    healthCandidateSinceMs = nowMs;
  }
  healthStable = static_cast<uint32_t>(nowMs - healthCandidateSinceMs) >=
                 HEALTH_STABLE_MS;
}

autonomy::Inputs collectInputs(uint32_t nowMs, bool runAlreadyStarted) {
  autonomy::Inputs inputs;
  inputs.nowMs = nowMs;
#if BUBBLEGUM_ENABLE_ACTUATION
  inputs.driveFeedbackAvailable = true;
  inputs.appliedDrivePermille = appliedDrivePermille;
#endif
  inputs.buttonPressed = digitalRead(board::START_BUTTON_PIN) == LOW;
  inputs.startupFrontClearRecent = startupFrontClearHeld;
  inputs.imu.online = imuSensors.bnoOnline();
  inputs.imu.valid = imuSensors.bnoSampleCount() > 0U;
  inputs.imu.accuracy = imuSensors.bnoAccuracy();
  inputs.imu.yawDegrees = imuSensors.yawDegrees();
  inputs.imu.updatedAtMs = imuSensors.lastBnoReadMs();
  inputs.front = rangeReading(tof.front());
  inputs.sides[autonomy::FrontLeft] = rangeReading(tof.frontLeft());
  inputs.sides[autonomy::BackLeft] = rangeReading(tof.backLeft());
  inputs.sides[autonomy::FrontRight] = rangeReading(tof.frontRight());
  inputs.sides[autonomy::BackRight] = rangeReading(tof.backRight());

  const bool heartbeatReady = visionDecoder.heartbeatReadyAndFresh(
      nowMs, controller.config().visionStaleMs);
  inputs.vision.online = heartbeatReady;
  if (visionDecoder.haveObservation()) {
    const vision::Observation& observation = visionDecoder.observation();
    inputs.vision.valid = observation.has(vision::CameraValid);
    inputs.vision.pipelineOverrun =
        observation.has(vision::PipelineOverrun);
    inputs.vision.frameQuality = observation.frameQuality;
    // This makes the controller's age check include processing time as well
    // as time since the ESP32 received the packet.
    inputs.vision.updatedAtMs =
        observation.receivedAtMs - observation.processingAgeMs;
    inputs.vision.red = blobReading(
        observation.red, observation.has(vision::RedPresent));
    inputs.vision.green = blobReading(
        observation.green, observation.has(vision::GreenPresent));
    // Parking markers are an atomic pair. The V1 decoder validates each slot,
    // while this consumer additionally refuses a one-sided packet.
    const bool magentaPairPresent =
        observation.has(vision::MagentaLeftPresent) &&
        observation.has(vision::MagentaRightPresent);
    inputs.vision.magentaLeft =
        blobReading(observation.magentaLeft, magentaPairPresent);
    inputs.vision.magentaRight =
        blobReading(observation.magentaRight, magentaPairPresent);
  }

  // Before the button, require one uninterrupted second of complete health.
  // After the run starts, expose each real status so any dropout latches.
  if (!runAlreadyStarted && !healthStable) {
    inputs.imu.online = false;
    inputs.front.online = false;
    for (autonomy::RangeReading& side : inputs.sides) side.online = false;
    inputs.vision.online = false;
  }
  return inputs;
}

void pollK230(uint32_t nowMs) {
  while (k230Serial.available() > 0) {
    visionDecoder.consume(static_cast<uint8_t>(k230Serial.read()), nowMs);
  }
}

void printRangeCsv(const TofSensors::Sample& sample) {
  if (sample.valid && sample.sampleCount > 0U) {
    Serial.print(sample.rangeMm);
  } else {
    Serial.print(-1);
  }
}

void printRangeTelemetryCsv(const TofSensors::Sample& sample,
                            uint32_t nowMs) {
  printRangeCsv(sample);
  Serial.print(',');
  Serial.print(sample.rangeStatus);
  Serial.print(',');
  Serial.print(sample.i2cStatus);
  Serial.print(',');
  if (sample.sampleCount > 0U) {
    Serial.print(static_cast<uint32_t>(nowMs - sample.lastUpdateMs));
  } else {
    Serial.print(-1);
  }
}
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
void loop() {
#if !BUBBLEGUM_ENABLE_ACTUATION
  forceOutputsLow();
#endif
  const uint32_t sensorPollMs = millis();

  pollK230(sensorPollMs);
  imuSensors.poll(sensorPollMs, Serial);
  tof.poll(sensorPollMs);

  // Use time captured after potentially blocking sensor I/O for every
  // freshness decision and controller update.
  const uint32_t nowMs = millis();
  updateHealthGate(nowMs);

  const bool runAlreadyStarted = controller.decision().startLatched;
  const autonomy::Inputs inputs = collectInputs(nowMs, runAlreadyStarted);
  const autonomy::Decision decision = controller.update(inputs);
  const bool justStarted = decision.startLatched && !previousStartLatched;
  if (justStarted) ++currentRunId;
  previousStartLatched = decision.startLatched;

  printEventChanges(nowMs, decision);
  const bool outputsStopped = applyDecision(nowMs, decision);

#if BUBBLEGUM_ENABLE_ACTUATION
  const runblackbox::Summary summary = blackBoxSummary(inputs, decision);
  if (justStarted) {
    runBlackBox.startRun(nowMs, summary, Serial);
  }
  runBlackBox.observe(nowMs, summary);
  if (decision.state == autonomy::RunState::Finished) {
    runBlackBox.persistTerminal(runblackbox::TerminalStatus::Finished,
                                outputsStopped, Serial);
  } else if (decision.state == autonomy::RunState::FaultLatched ||
             actuatorFault) {
    // An actuator fault is also terminal at the vehicle level: applyDecision()
    // has already latched the driver off even if the pure controller has not
    // independently raised a sensor/navigation fault.
    runBlackBox.persistTerminal(runblackbox::TerminalStatus::FaultLatched,
                                outputsStopped, Serial);
  } else if (justStarted) {
    const bool insideServoSettle =
        actuatorsStarted &&
        static_cast<uint32_t>(nowMs - actuatorsStartedAtMs) < SERVO_SETTLE_MS;
    runBlackBox.persistActive(outputsStopped && insideServoSettle, Serial);
  }
#else
  (void)justStarted;
  (void)outputsStopped;
#endif

  if (static_cast<uint32_t>(nowMs - lastTelemetryMs) >=
      TELEMETRY_INTERVAL_MS) {
    lastTelemetryMs = nowMs;
    printTelemetry(nowMs, inputs, decision);
  }
  if (static_cast<uint32_t>(nowMs - lastSensorSummaryMs) >=
      SENSOR_SUMMARY_INTERVAL_MS) {
    lastSensorSummaryMs = nowMs;
    tof.printSummary(Serial, nowMs);
    imuSensors.printSummary(Serial, nowMs);
    const vision::DecoderStats& stats = visionDecoder.stats();
    Serial.print(F("[k230] observations="));
    Serial.print(stats.validObservations);
    Serial.print(F(" crc_bad="));
    Serial.print(stats.crcErrors);
    Serial.print(F(" payload_bad="));
    Serial.print(stats.payloadErrors);
    Serial.print(F(" dropped="));
    Serial.println(stats.droppedFrames);
  }

#if !BUBBLEGUM_ENABLE_ACTUATION
  forceOutputsLow();
#endif
  yield();
}

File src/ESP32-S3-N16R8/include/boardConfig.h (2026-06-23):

#pragma once

#include <Arduino.h>

// ESP32-S3-WROOM-1-N16R8 hardware map. The default dryRun build executes the
// full controller but compiles the actuator implementation out. Motion code is
// available only in the explicitly selected autonomous environment.
namespace board {

// The current harness uses one IBT-2 on GPIO10/11/12. The dryRun build forces
// every one of these pins LOW.
constexpr uint8_t DRIVE_ENABLE_PIN = 10;  // R_EN and L_EN tied together
constexpr uint8_t DRIVE_RPWM_PIN = 11;
constexpr uint8_t DRIVE_LPWM_PIN = 12;
constexpr uint8_t MOTOR_SAFE_PINS[] = {
    DRIVE_ENABLE_PIN,
    DRIVE_RPWM_PIN,
    DRIVE_LPWM_PIN,
};

// The dryRun firmware holds this pin LOW. A constant LOW is not a valid
// RC-servo command pulse; the autonomous build generates bounded PWM.
constexpr uint8_t STEERING_SERVO_PIN = 13;

// Three physical I2C harnesses share only two ESP32-S3 hardware controllers.
// Wire stays dedicated to XMS-A5, Wire1 stays dedicated to all five ToF
// modules, and the backup MPU6050 uses software I2C on its independent GPIO8/9
// harness. No live hardware controller is rebound between sensors.
constexpr uint8_t MPU_I2C_SDA_PIN = 8;
constexpr uint8_t MPU_I2C_SCL_PIN = 9;
constexpr uint8_t TOF_I2C_SDA_PIN = 5;
constexpr uint8_t TOF_I2C_SCL_PIN = 6;
constexpr uint32_t I2C_CLOCK_HZ = 400000;
constexpr uint16_t I2C_TIMEOUT_MS = 20;

constexpr uint8_t K230_UART_RX_PIN = 18;  // connect to K230 TX
constexpr uint8_t K230_UART_TX_PIN = 17;  // connect to K230 RX
constexpr uint32_t K230_UART_BAUD = 115200;

constexpr uint8_t START_BUTTON_PIN = 4;  // button to GND, INPUT_PULLUP

// All five ST sensors boot at 0x29.  XSHUT is therefore required to wake and
// re-address them one at a time.  Driving XSHUT LOW holds a sensor in reset;
// INPUT releases it high-Z so the module's own pull-up can wake it.
constexpr uint8_t TOF_DEFAULT_ADDRESS = 0x29;
constexpr uint8_t TOF_FRONT_XSHUT_PIN = 15;
constexpr uint8_t TOF_FRONT_LEFT_XSHUT_PIN = 39;
constexpr uint8_t TOF_BACK_LEFT_XSHUT_PIN = 40;
constexpr uint8_t TOF_FRONT_RIGHT_XSHUT_PIN = 41;
constexpr uint8_t TOF_BACK_RIGHT_XSHUT_PIN = 42;

constexpr uint8_t TOF_FRONT_ADDRESS = 0x30;
constexpr uint8_t TOF_FRONT_LEFT_ADDRESS = 0x31;
constexpr uint8_t TOF_BACK_LEFT_ADDRESS = 0x32;
constexpr uint8_t TOF_FRONT_RIGHT_ADDRESS = 0x33;
constexpr uint8_t TOF_BACK_RIGHT_ADDRESS = 0x34;

// The purple GY-BNO08X carrier was physically identified as an XMS-A5 that is
// BNO055-compatible. It is therefore run in I2C mode, not BNO08x SPI mode.
// PS1 is physically connected to GND. Firmware holds PS0 and ADDR LOW, CS HIGH,
// and uses RST for a deterministic startup. GPIO19/20 are USB D-/D+, so use
// the board's separate USB-to-UART COM connector while this harness is fitted.
constexpr uint8_t XMS_A5_I2C_SDA_PIN = 20;
constexpr uint8_t XMS_A5_I2C_SCL_PIN = 19;
constexpr uint8_t XMS_A5_ADDR_PIN = 21;
constexpr uint8_t XMS_A5_CS_PIN = 47;
constexpr uint8_t XMS_A5_INT_PIN = 48;
constexpr uint8_t XMS_A5_RST_PIN = 2;
constexpr uint8_t XMS_A5_PS0_PIN = 38;
constexpr uint8_t XMS_A5_I2C_ADDRESS = 0x28;
constexpr uint32_t XMS_A5_I2C_CLOCK_HZ = 100000;

constexpr uint8_t MPU6050_ADDRESS = 0x68;

#ifndef BUBBLEGUM_ENABLE_MPU6050_COMPARISON
#define BUBBLEGUM_ENABLE_MPU6050_COMPARISON 1
#endif

constexpr bool ENABLE_MPU6050_COMPARISON =
    BUBBLEGUM_ENABLE_MPU6050_COMPARISON != 0;

constexpr uint32_t SENSOR_SUMMARY_INTERVAL_MS = 500;
constexpr uint32_t TOF_STALE_AFTER_MS = 250;
constexpr uint32_t IMU_SAMPLE_INTERVAL_MS = 100;
constexpr uint32_t VISION_SUMMARY_INTERVAL_MS = 250;
constexpr uint32_t VISION_FRESH_MAX_AGE_MS = 250;

constexpr uint8_t ALL_ASSIGNED_PINS[] = {
    DRIVE_ENABLE_PIN,
    DRIVE_RPWM_PIN,
    DRIVE_LPWM_PIN,
    STEERING_SERVO_PIN,
    MPU_I2C_SDA_PIN,
    MPU_I2C_SCL_PIN,
    TOF_I2C_SDA_PIN,
    TOF_I2C_SCL_PIN,
    K230_UART_RX_PIN,
    K230_UART_TX_PIN,
    START_BUTTON_PIN,
    TOF_FRONT_XSHUT_PIN,
    TOF_FRONT_LEFT_XSHUT_PIN,
    TOF_BACK_LEFT_XSHUT_PIN,
    TOF_FRONT_RIGHT_XSHUT_PIN,
    TOF_BACK_RIGHT_XSHUT_PIN,
    XMS_A5_I2C_SDA_PIN,
    XMS_A5_I2C_SCL_PIN,
    XMS_A5_ADDR_PIN,
    XMS_A5_CS_PIN,
    XMS_A5_INT_PIN,
    XMS_A5_RST_PIN,
    XMS_A5_PS0_PIN,
};

constexpr bool assignedPinsAreUnique() {
  constexpr size_t pinCount =
      sizeof(ALL_ASSIGNED_PINS) / sizeof(ALL_ASSIGNED_PINS[0]);
  for (size_t i = 0; i < pinCount; ++i) {
    for (size_t j = i + 1U; j < pinCount; ++j) {
      if (ALL_ASSIGNED_PINS[i] == ALL_ASSIGNED_PINS[j]) return false;
    }
  }
  return true;
}
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

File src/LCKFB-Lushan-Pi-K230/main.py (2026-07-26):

"""K230 vision program for WRO traffic signs and parking markers.

Run this standalone file from RAM first with the CanMV VS Code extension. It
sends observations to the ESP32 through the pictured 40-pin UART header. The
ESP32 makes the steering and speed decisions. The values sent by this program
describe image geometry, not distance in cm.

The filtering and temporal-tracking code stays importable on a host computer
so its exact board logic can be tested without importing CanMV media modules.
The current production profile uses only red/green pillars; parking telemetry
is experimental and disabled below.
"""

import gc

try:
    import ustruct as struct
except ImportError:
    import struct


FRAME_WIDTH = 320
FRAME_HEIGHT = 240
PREVIEW_FPS = 15
PREVIEW_DIVISOR = 4
# Production default: no USB preview or overlay work in the driving loop.
# Change this one value to True only for a tethered CanMV calibration session;
# perception logic stays the same, but preview load can change timing/overrun
# diagnostics and must not be used for a driving performance claim.
ENABLE_IDE_PREVIEW = False

# Parking control is disabled in the current ESP32 Obstacle profile. Keep the
# extra full-frame colour scan off in production until the pair geometry has
# been validated from the mounted camera. When explicitly enabled, protocol
# "left/right" means image-left/image-right only, not a physical bay side.
ENABLE_EXPERIMENTAL_PARKING_TELEMETRY = False

# K230 -> ESP32 vision link through the pictured 40-pin header. Physical pin
# 11 is K230 GPIO5/UART2 TX, physical pin 13 is GPIO6/UART2 RX, and physical
# pin 14 is GND. Cross TX/RX at the ESP32. Never connect a 40-pin-header power
# pin between the boards; power the K230 separately through USB-C for IDE work
# or its dedicated 8-24 V input for offline use.
ENABLE_UART_LINK = True
UART_BAUDRATE = 115200
UART_TX_GPIO = 5
UART_RX_GPIO = 6
UART_HEARTBEAT_INTERVAL_MS = 100
PIPELINE_OVERRUN_AGE_MS = 80
UART_OBSERVATION_FRAME_BYTES = 66
UART_OBSERVATION_WIRE_TIME_MS = (
    UART_OBSERVATION_FRAME_BYTES * 10 * 1000 + UART_BAUDRATE - 1
) // UART_BAUDRATE

# Minimal embedded copy of protocol V1. The RAM-run tracker deliberately has
# no sibling-file import because CanMV does not upload protocol/ automatically.
UART_SYNC = b"\xA5\x5A"
UART_VERSION = 1
UART_TYPE_HEARTBEAT = 0x01
UART_TYPE_OBSERVATION = 0x10
UART_ROLE_K230 = 1
UART_STATE_BOOT = 0
UART_STATE_READY = 1
UART_STATE_DEGRADED = 2
UART_UNKNOWN_SEQUENCE = 0xFFFF
UART_UNKNOWN_RANGE_MM = 0xFFFF
UART_ERROR_LOOP_OVERRUN = 1 << 1
UART_ERROR_CONFIG_INVALID = 1 << 7
UART_FLAG_CAMERA_VALID = 1 << 0
UART_FLAG_RED_PRESENT = 1 << 4
UART_FLAG_GREEN_PRESENT = 1 << 5
UART_FLAG_MAGENTA_LEFT_PRESENT = 1 << 6
UART_FLAG_MAGENTA_RIGHT_PRESENT = 1 << 7
UART_FLAG_PIPELINE_OVERRUN = 1 << 8
UART_FLAG_EXPOSURE_UNSTABLE = 1 << 9
UART_OBSERVATION_PAYLOAD_SIZE = 52
UART_MAX_WRITE_ERRORS = 0xFFFF

# Starting values from a properly illuminated desk scene. The competition-day
# calibrator stores replacements on the SD card. Production tries the primary
# file, then its last-known-good backup, and finally these compiled defaults.
COLOR_CONFIG_LEGACY_MAGIC = "BUBBLEGUM_COLOR_V1"
COLOR_CONFIG_MAGIC = "BUBBLEGUM_COLOR_V2"
COLOR_CONFIG_PATH = "/sdcard/colorThresholds.cfg"
COLOR_CONFIG_BACKUP_PATH = "/sdcard/colorThresholds.bak"
COLOR_CONFIG_MAX_BYTES = 320
DEFAULT_RED_LAB = (30, 72, 20, 68, 7, 58)
DEFAULT_GREEN_LAB = (30, 75, -48, -14, 15, 68)
# A calibrated threshold must stay clearly on the expected side of neutral
# LAB A.  The margin rejects a white/grey sample that merely happens to be
# separated from the red box, while retaining the latest field calibration
# (red A 24..47, green A -33..-10) and the compiled diagnostic defaults.
MIN_RED_A_LOW = 8
MAX_GREEN_A_HIGH = -8
RED_LAB = DEFAULT_RED_LAB
GREEN_LAB = DEFAULT_GREEN_LAB
MAGENTA_LAB = None
RED_THRESHOLDS = [RED_LAB]
GREEN_THRESHOLDS = [GREEN_LAB]
MAGENTA_THRESHOLDS = []

# The official traffic sign is 50 x 50 x 100 mm, so an unobstructed image is
# expected to be upright and roughly twice as tall as it is wide.
MIN_PIXELS = 24
MIN_AREA = 32
MIN_DENSITY_100 = 32
MIN_BOTTOM_PX = 48
MAX_CANDIDATES = 6
# CanMV materializes find_blobs() before Python can copy a bounded subset. A
# cluttered frame therefore fails closed before scoring/tracking and also caps
# Python-side scan time. The mounted ROI and LAB calibration remain the real
# controls for native allocation pressure.
MAX_RAW_BLOBS_PER_COLOR = 32

# Search only the configurable track region. The default is deliberately the
# full frame: cropping at the old base threshold would cut the top off a real
# pillar whose base is valid. Narrow this only from mounted-camera field images.
# CanMV's ROI is (x, y, width, height).
TRACK_ROI_X = 0
TRACK_ROI_Y = 0
TRACK_ROI_W = FRAME_WIDTH
TRACK_ROI_H = FRAME_HEIGHT - TRACK_ROI_Y
TRACK_ROI = (TRACK_ROI_X, TRACK_ROI_Y, TRACK_ROI_W, TRACK_ROI_H)

# A valid sign must end on the searched track/ground region. Keeping this
# separate from TRACK_ROI makes an intentional track calibration visible and
# preserves fail-closed behavior if the ROI is later widened for debugging.
GROUND_BASE_MIN_Y = MIN_BOTTOM_PX
GROUND_BASE_MAX_Y = TRACK_ROI_Y + TRACK_ROI_H - 1

# Edge clipping relaxes aspect ratio only for plausible close pillars. These
# hard limits still reject a wall/card that reaches an image edge.
HARD_MAX_WIDTH_PERCENT = 60
HARD_MAX_AREA_PERCENT = 35
RELAXED_MAX_WIDTH_PERCENT = 50
RELAXED_MAX_AREA_PERCENT = 22
RELAXED_MIN_DENSITY_100 = 55

# This dimensionless score combines upright geometry, fill, bounded size, and
# ground position below. It is intentionally not a LAB calibration value.
# Raise it only after reviewing raw-candidate overlays on the mounted camera.
MIN_CANDIDATE_QUALITY = 45

# Association limits are deliberately hard-capped. A large nearby box must
# not make the gate wide enough to jump to another same-color pillar.
MAX_ASSOC_X_PX = 48
MAX_ASSOC_BASE_PX = 72
MAX_ASSOC_AREA_RATIO = 3

# A report requires consecutive associated detections. Briefly retain a
# confirmed target for overlays through an occlusion, but stale memory is
# never put on UART and therefore never controls steering.
TRACK_CONFIRM_HITS = 3
TRACK_OCCLUSION_MEMORY_FRAMES = 2
UNCONFIRMED_MISS_LIMIT = 1
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

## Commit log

2026-06-07 docs: add CAD model readme
2026-06-09 assets: add Fusion 360 chassis assembly
    [Ackermann Chassis CLEAN Named Assembly.f3z]
2026-06-12 docs: add wiring overview readme
2026-06-14 assets: add wiring overview diagram (excalidraw and png)
2026-06-17 chore: add bill of materials
    [bom.csv]
2026-06-20 build: add PlatformIO skeleton for ESP32-S3
2026-06-23 feat(board): add board pin and hardware configuration
2026-06-26 feat(vision): add UART vision protocol layer
2026-06-29 feat(sensors): add BNO055 IMU driver
2026-07-02 feat(sensors): add VL53 ToF distance driver
2026-07-05 chore(vendor): add VL53L4CD sensor library
2026-07-08 feat(actuators): add servo steering and motor control
2026-07-20 feat(firmware): add ESP32 main loop
2026-07-23 docs: add K230 vision board readme
2026-08-13 tools: add K230 production install and calibration tooling
